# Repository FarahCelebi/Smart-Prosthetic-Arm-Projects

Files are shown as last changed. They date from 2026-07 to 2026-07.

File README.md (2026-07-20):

## Smart Prosthetic Arm

A six-project open hardware and firmware system for a surface EMG-controlled
prosthetic arm. The system reads muscle electrical signals from surface
electrodes, classifies hand gestures in real time, and drives a
servo-actuated prosthetic hand accordingly. Each project is a self-contained,
fully documented deliverable — schematic, PCB layout, Gerbers, and README —
designed to be fabricated and tested independently before integration.

## System Architecture

```
Surface electrodes
       │
       ▼
┌─────────────────┐
│  Project 1      │  EMG Acquisition Board
│  EMG signals    │  Dual-channel INA333 + ADS1115
│  → I²C out      │  Gain ~404×, 16-bit ADC
└────────┬────────┘
         │ I²C
         ▼
┌─────────────────┐
│  Project 2      │  Gesture Classifier Firmware
│  STM32 firmware │  Real-time EMG feature extraction
│  → gesture ID   │  + ML-based gesture classification
└────────┬────────┘
         │ I²C / UART
         ▼
┌─────────────────┐     ┌─────────────────┐
│  Project 3      │     │  Project 4      │
│  Servo Driver   │     │  BLE Module     │
│  PCA9685 PWM    │     │  nRF52840       │
│  6× servo out   │     │  Wireless telem │
└────────┬────────┘     └─────────────────┘
         │
         ▼
┌─────────────────┐
│  Project 5      │  IMU + EMG Sensor Fusion
│  ICM-42688-P    │  Accelerometer + gyroscope
│  + sensor fusion│  fused with EMG for robustness
└────────┬────────┘
         │
         ▼
┌─────────────────┐
│  Project 6      │  Full Integration Capstone
│  All subsystems │  Complete assembled arm system
│  integrated     │  End-to-end validation
└─────────────────┘
```

## Projects

| # | Project | Type | Description |
|---|---|---|---|
| 01 | [EMG Acquisition Board](./Project-1-EMG-Acquisition) | PCB | Dual-channel surface EMG acquisition board using INA333 instrumentation amplifiers and an ADS1115 16-bit ADC. Conditions raw muscle signals through a 404× gain chain with high-pass filtering and anti-alias filtering before I²C output. |
| 02 | [Gesture Classifier Firmware](./Project-2-Gesture-Classifier) | Firmware | Real-time gesture classification firmware running on the STM32F411, fusing dual-channel EMG features with ICM-42688-P IMU data to classify six hand gestures. Outputs servo position commands over I²C and streams telemetry to the BLE module over UART. |
| 03 | [Servo Driver Board](./Project-3-Servo-Driver) | PCB | PCA9685-based 16-channel PWM controller driving six servo motors for prosthetic hand finger and wrist actuation over I²C. Separate 5–6V servo power rail with 2000µF bulk capacitance isolates motor switching transients from the logic supply. |
| 04 | [BLE Telemetry Module](./Project-4-BLE-Telemetry-Module) | PCB | Bare nRF52840-QIAA BLE 5.0 transceiver board with full RF front-end design including pi-network antenna matching and quarter-wave wire antenna. Accepts USB or LiPo power through a dual-input OR-ing diode circuit with a low-dropout XC6210 LDO. |
| 05 | [IMU + EMG Sensor Fusion](./Project-5-IMU+EMG-Sensor-Fusion) | PCB | ICM-42688-P 6-axis IMU board providing wrist orientation and motion data over high-speed SPI to complement EMG signals in the gesture classifier. Includes an I²C passthrough header matching the EMG board pinout for minimal wiring harness on the arm. |
| 06 | [Full Integration Capstone](./Project-6-Full-Integration-Capstone) | PCB + Firmware | Central hub board hosting the STM32F411 main MCU and routing power, I²C, SPI, and UART signals between all five subsystem boards through pinout-matched connectors. Runs the gesture classifier firmware and coordinates the complete prosthetic arm system from a single 3.7V LiPo cell. |

## Hardware Stack

| Component | Role |
|---|---|
| INA333 (×2) | Instrumentation amplifier |
| ADS1115 | 16-bit I²C ADC |
| TLV2372 | Second-stage op-amp |
| PCA9685PW | 16-channel PWM servo controller |
| nRF52840 | BLE 5.0 + ARM Cortex-M4 |
| ICM-42688-P | 6-axis IMU (accelerometer + gyroscope) |

## Tools

- KiCad (PCB design)
- GitHub Desktop (version control)
- Zephyr RTOS / STM32 HAL (firmware)

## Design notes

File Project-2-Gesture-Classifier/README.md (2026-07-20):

# Gesture-Classifier-Firmware

Real-time hand gesture classification firmware for the Smart Prosthetic Arm
system, designed as Project 2 of 6. Running on the STM32F411RETx integration
board, the firmware reads dual-channel EMG signals from the ADS1115 ADC over
I²C, reads 6-axis inertial data from the ICM-42688-P IMU over SPI, fuses
both sensor streams to classify one of six hand gestures, drives the PCA9685
servo controller over I²C to actuate the prosthetic hand, and streams
telemetry to the nRF52840 BLE module over UART — all in a continuous
real-time loop.

## Repository Structure

```
Project-2-Gesture-Classifier/
├── README.md
└── Integration-Capstone/
    └── Core/
        ├── Inc/
        │   ├── emg.h
        │   ├── imu.h
        │   ├── classifier.h
        │   ├── servo.h
        │   └── ble.h
        └── Src/
            ├── main.c
            ├── emg.cpp
            ├── imu.cpp
            ├── classifier.cpp
            ├── servo.cpp
            └── ble.cpp
```

## System Architecture

```
ADS1115 (I²C1, 0x48)          ICM-42688-P (SPI1)
        │                              │
        ▼                              ▼
  emg.cpp                        imu.cpp
  - Read CH0, CH1                - Read accel x/y/z
  - Collect 200-sample window    - Read gyro x/y/z
  - Compute RMS, MAV             - Scale to g and °/s
        │                              │
        └──────────┬───────────────────┘
                   ▼
            classifier.cpp
            - Threshold-based gesture ID
            - 6 gestures: REST, GRIP, PINCH,
              POINT, PRONATE, SUPINATE
                   │
        ┌──────────┴──────────┐
        ▼                     ▼
   servo.cpp              ble.cpp
   PCA9685 (I²C1, 0x40)  nRF52840 (UART1)
   6-channel PWM          Telemetry packet
   finger/wrist control   G, E1, E2, AX, AY, AZ, GZ
```

## Gesture Definitions

| ID | Gesture | EMG Signature | IMU Signature |
|---|---|---|---|
| 0 | REST | Both channels quiet (<200 RMS) | Any |
| 1 | GRIP | Both channels active (>400 RMS) | Neutral |
| 2 | PINCH | CH2 dominant (>1.5× CH1) | Neutral |
| 3 | POINT | CH1 dominant (>1.5× CH2) | Neutral |
| 4 | PRONATE | CH1 moderate | Gyro Z > +50 °/s |
| 5 | SUPINATE | CH1 moderate | Gyro Z < -50 °/s |

## Design Notes

**Two-phase classifier architecture:** Phase 1 (this implementation) uses a
threshold-based classifier — fast, deterministic, and requires no training
data. EMG features (RMS and MAV per channel) are computed over a 200-sample
window at 860 SPS from the ADS1115, giving a feature update rate of
approximately 4Hz. IMU data is sampled once per gesture cycle. Phase 2 will
replace the threshold classifier with a support vector machine or lightweight
neural network trained on labelled EMG/IMU data collected using the SDMMC
Logger board (Project 3), improving classification accuracy for ambiguous
gestures.

**Sensor fusion rationale:** Surface EMG signals alone cannot reliably
distinguish pronation from supination or wrist-neutral gestures, since the
forearm muscle activation patterns overlap. The ICM-42688-P gyroscope Z-axis
provides the wrist rotation signal that resolves this ambiguity — the IMU
acts as a tie-breaker for gestures that EMG features cannot separate cleanly.

**EMG feature extraction:** Two features are computed per channel per window.
RMS (root mean square) captures signal energy and correlates with muscle
contraction force. MAV (mean absolute value) is computationally cheaper and
tracks signal amplitude. Both are computed in emg.cpp using integer
accumulation before a single sqrtf call, minimising floating point load on
the Cortex-M4F.

**ADS1115 sampling:** The ADS1115 is operated in single-shot mode at 860
SPS. Each channel conversion is triggered by writing the config register,
followed by a 2ms delay and a register read. With 200 samples per channel
per window, total EMG acquisition time is approximately 800ms per cycle.
Future optimisation will use the ALERT/RDY pin for interrupt-driven sampling,
removing the HAL_Delay calls and enabling higher effective sample rates.

**ICM-42688-P interface:** The IMU is read over SPI1 at 8MHz. A burst read
of 12 bytes starting at the accelerometer output register retrieves all six
axes in one transaction. Raw 16-bit values are scaled to g (accel,
±2g range, 16384 LSB/g) and degrees per second (gyro, ±250°/s range,
131 LSB/°/s).

**PCA9685 servo control:** The PCA9685 is configured for 50Hz PWM output
using an internal prescaler value of 121. Each servo channel is set using
a pulse width between 205 counts (~1ms, full open) and 410 counts (~2ms,
full close), with 307 counts (~1.5ms) as the neutral position. Six channels
(LED0–LED5) drive one servo per finger and wrist.

**BLE telemetry format:** Each telemetry packet is a null-terminated ASCII
string transmitted over UART1 at 115200 baud to the nRF52840 BLE module.
Format: `G:%d,E1:%d,E2:%d,AX:%d,AY:%d,AZ:%d,GZ:%d\r\n` where EMG RMS
values are integer counts, accelerometer values are scaled ×100 (cm/s²
units), and gyroscope Z is scaled ×10 (0.1°/s units). Float formatting
is avoided as `--specs=nano.specs` disables float printf support by default
in the ARM GCC nano libc.

**Build system:** The project is generated by STM32CubeMX and built from
the Terminal using the GNU ARM toolchain bundled with STM32CubeIDE. C HAL
files are compiled with arm-none-eabi-gcc; application modules (emg.cpp,
imu.cpp, classifier.cpp, servo.cpp, ble.cpp) and main.c are compiled with
arm-none-eabi-g++ to enable C++14 features and resolve C/C++ Thumb
interworking. The final ELF is linked with arm-none-eabi-g++.

## Build Instructions

```bash
# Add toolchain to PATH (adjust version as needed)
export PATH="/Applications/STM32CubeIDE.app/Contents/Eclipse/plugins/\
com.st.stm32cube.ide.mcu.externaltools.gnu-tools-for-stm32.14.3.rel1.\
macosaarch64_1.0.0.202602081740/tools/bin:$PATH"

cd Integration-Capstone/Debug
make all
```

## Flash Instructions

Connect an ST-LINK V2 to the SWD header (J3 on the Integration Capstone
Board) and use STM32CubeProgrammer or the CubeIDE debugger to flash
`Integration-Capstone.elf`.

## Binary Size (Phase 1)

| Section | Size |
|---|---|
| text (flash) | 47,824 bytes |
| data (initialized) | 332 bytes |
| bss (zero-initialized RAM) | 9,388 bytes |

## Hardware Dependencies

| Board | Role | Interface |
|---|---|---|
| EMG Acquisition Board | EMG signal source | I²C1 (0x48) |
| IMU Sensor Fusion Board | Motion data | SPI1 + PA4 CS |
| Servo Driver Board | Hand actuation | I²C1 (0x40) |
| BLE Module | Wireless telemetry | UART1 115200 |

## Part of

Smart Prosthetic Arm — Project 2 of 6

## Tools

- STM32CubeMX (peripheral configuration)
- STM32CubeIDE (project structure)
- GNU ARM Toolchain 14.3 (compilation)
- C++14

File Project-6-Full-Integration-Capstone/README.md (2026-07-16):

# Integration-Capstone-Board

The central hub of the Smart Prosthetic Arm system, designed as Project 6
of 6. This board hosts the main STM32F411RETx microcontroller and provides
the physical connectors, power distribution, and signal routing that ties
all five subsystem boards into a unified wearable system — the EMG
Acquisition Board, Servo Driver Board, BLE Module, IMU Sensor Fusion Board,
and the Gesture Classifier firmware running on the STM32 itself.

## Schematic

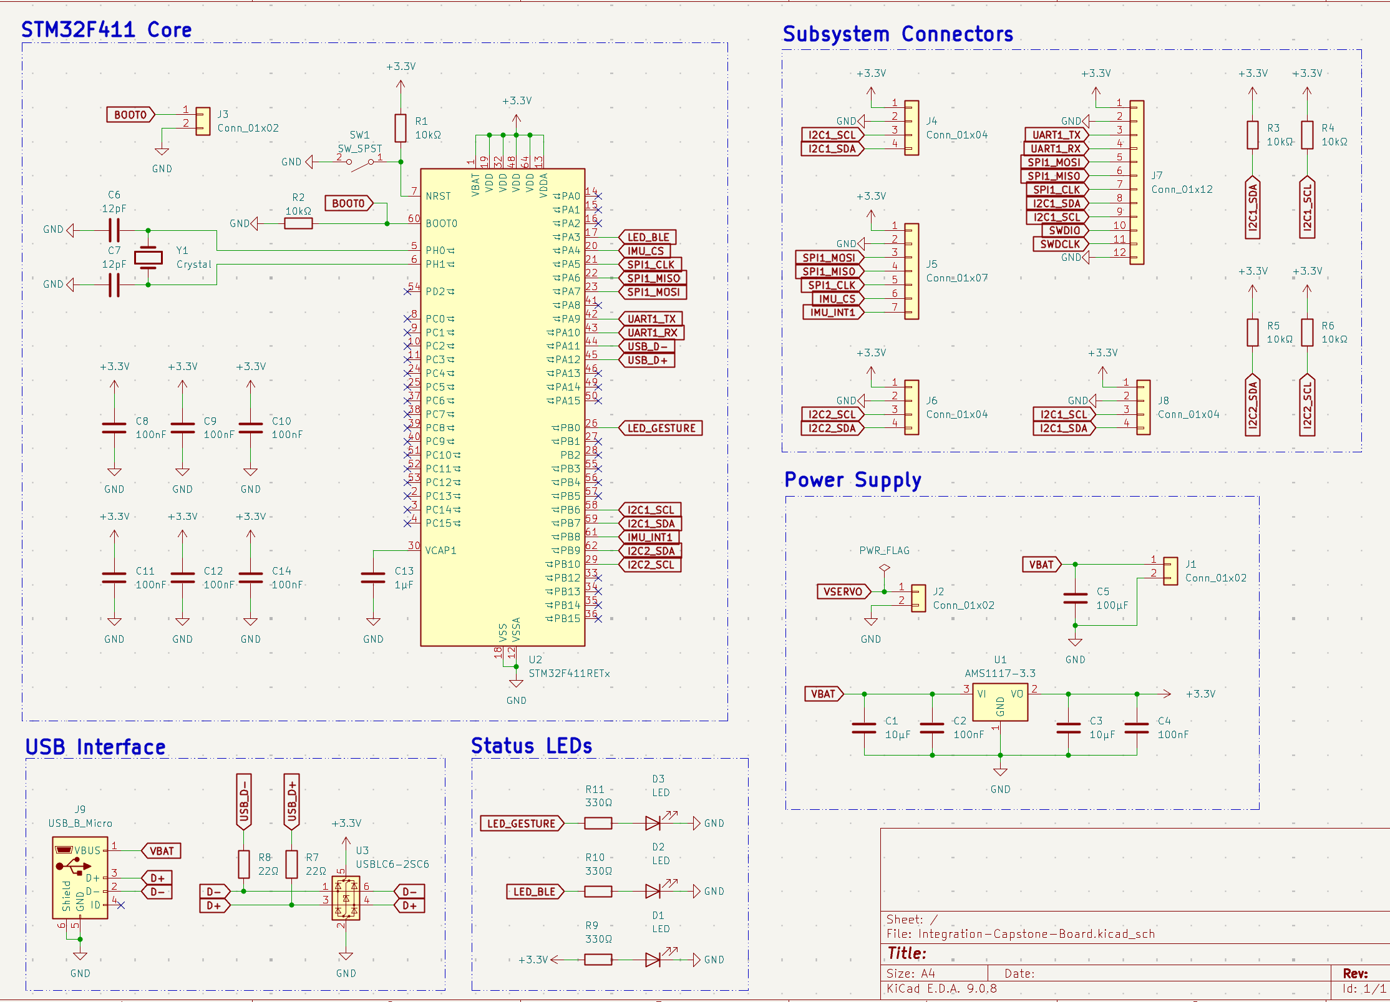
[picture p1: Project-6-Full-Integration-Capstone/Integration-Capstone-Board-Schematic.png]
Schematic


## PCB Layout

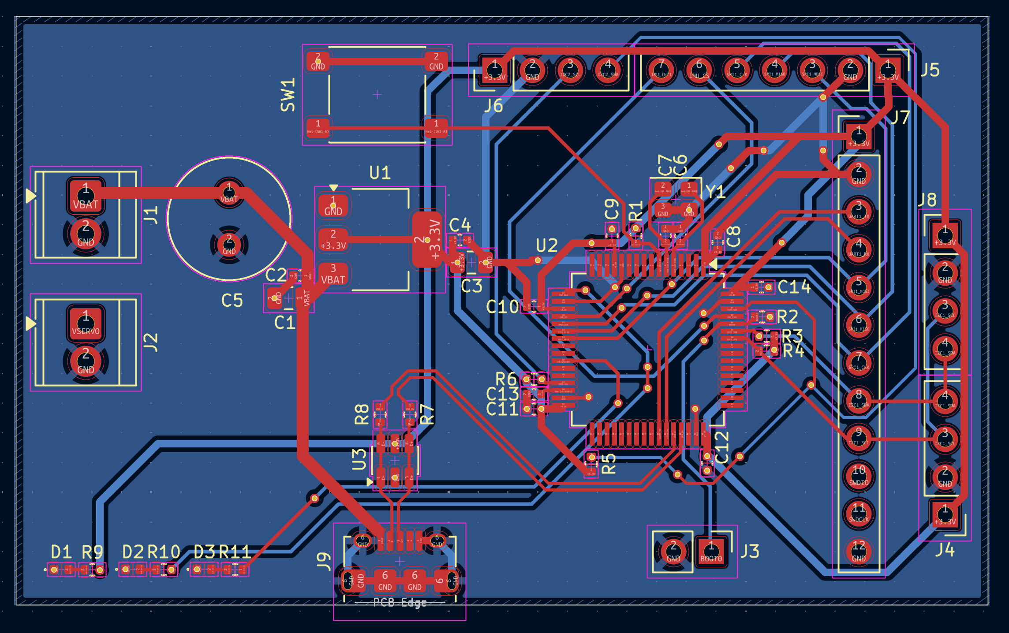
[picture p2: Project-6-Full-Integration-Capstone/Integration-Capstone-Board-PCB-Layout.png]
PCB Layout


## 3D View

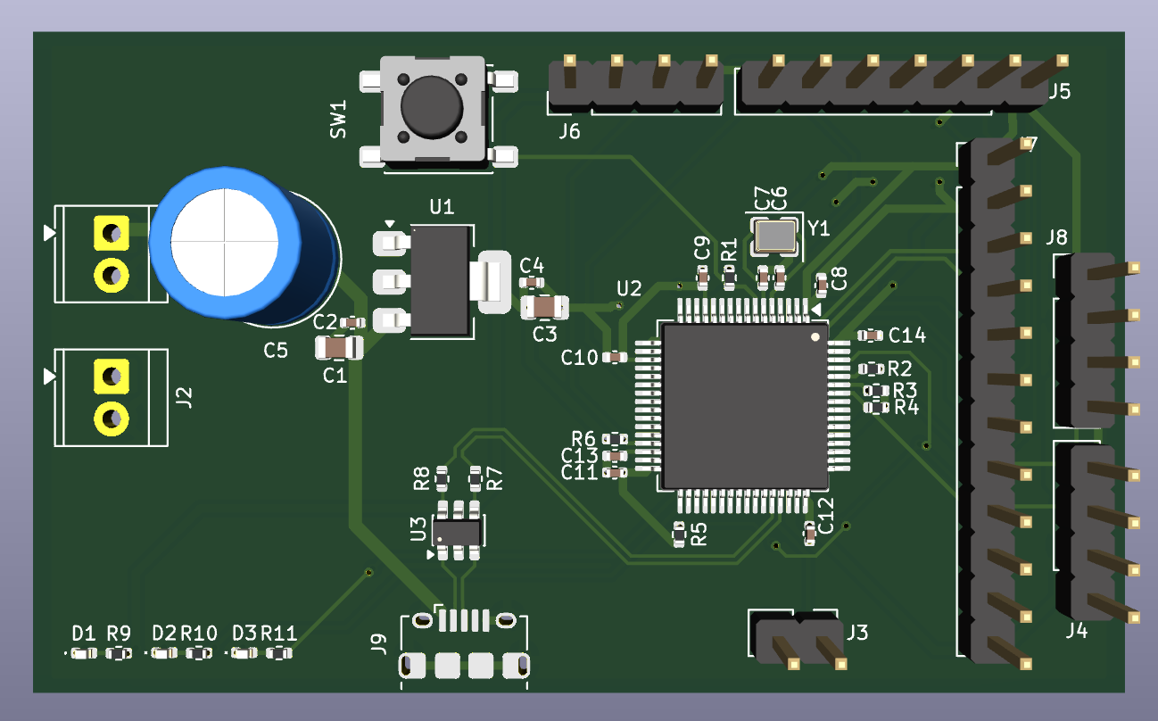
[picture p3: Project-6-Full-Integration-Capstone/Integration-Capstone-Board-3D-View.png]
3D View


## Overview

Rather than designing another standalone sensor or actuator board, the
capstone solves the real system integration challenge — making five
independent boards work together reliably as a wearable prosthetic arm.
The STM32F411 reads dual-channel EMG data from the ADS1115 over I²C,
reads 6-axis IMU data from the ICM-42688-P over SPI, classifies the
fused sensor data into one of six hand gestures, sends servo position
commands to the PCA9685 over I²C, and streams telemetry to the nRF52840
BLE module over UART — all concurrently, from a single board running on
a 3.7V LiPo battery.

## System Connections

| Connector | Subsystem | Interface | Pinout match |
|---|---|---|---|
| J4 | EMG Acquisition Board | I²C1 | Matches EMG board J3 |
| J5 | IMU Sensor Fusion Board | SPI1 + INT1 | Matches IMU board J2 |
| J6 | IMU I²C Passthrough | I²C2 | Matches IMU board J3 |
| J7 | BLE Module | UART1 + SPI1 + I²C1 + SWD | Matches BLE board J3 |
| J8 | Servo Driver Board | I²C1 | Matches servo driver J9 |
| J9 | USB | Programming + CDC | Micro-B |

All connector pinouts were designed from the start of the project to match
across boards — plugging any subsystem board into its corresponding header
requires no adapter and no rewiring.

## Design Notes

**Dual I²C bus architecture:** The STM32F411 has two I²C peripherals. I²C1
(PB6/PB7) is the main system bus, shared between the EMG Acquisition Board
(ADS1115, address 0x48), the Servo Driver Board (PCA9685, address 0x40),
and the BLE module's I²C lines. I²C2 (PB10/PB11) is a dedicated bus for
the IMU board's I²C passthrough header — isolating the IMU's local I²C
traffic from the main system bus prevents address conflicts and reduces bus
loading. Separate 10kΩ pull-up pairs (R3/R4 for I²C1, R5/R6 for I²C2)
are placed immediately beside their respective connectors.

**SPI bus sharing:** SPI1 (PA5/PA6/PA7) is shared between the IMU Sensor
Fusion Board (J5) and the BLE module (J7). The IMU chip select (IMU_CS on
PA4) and the BLE module's SPI CS are managed independently by the firmware,
allowing both devices on the same SPI bus without conflict. SPI was chosen
for the IMU over I²C to allow data rates up to 24MHz — necessary for high
ODR IMU sampling concurrent with BLE activity.

**Power architecture:** A single LiPo cell (3.7V nominal) connects to J1.
The AMS1117-3.3 LDO (U1) regulates this to 3.3V for the STM32, crystal,
and all subsystem connector power pins. A 100µF bulk electrolytic capacitor
(C5) is placed immediately at J1 to handle inrush current during system
startup when all five subsystem boards power up simultaneously. J2 is a
separate screw terminal for the 6V servo power rail — this passes directly
to the Servo Driver Board via cable and is never routed across the
integration board's PCB, keeping high-current servo switching noise isolated
from the logic rail.

**Crystal and USB:** A 25MHz crystal (Y1) provides the STM32's PLL
reference for accurate USB CDC operation. Load capacitors C6 and C7 (12pF
each) are placed immediately beside PH0 and PH1 with no vias on the
oscillator traces. USB D+ and D− pass through the USBLC6-2SC6 ESD
protection device (U3) placed immediately adjacent to J9, then through 22Ω
series resistors before reaching PA11 and PA12. The USB VBUS pin connects
to the VBAT net — when USB is connected it powers the board directly,
supplementing or replacing the LiPo without additional power management
circuitry.

**Reset and boot:** SW1 is a tactile push button connected to NRST with a
10kΩ pull-up to +3.3V, placed close to U2's NRST pin to minimise the reset
trace length. R2 pulls BOOT0 low by default for normal flash execution mode.
J3 is a 2-pin BOOT0 header that allows the STM32 to be put into DFU mode
by bridging pin 1 to +3.3V — used for initial firmware flashing before the
USB CDC interface is operational.

**Status LEDs:** Three LEDs provide system state visibility. D1 (green,
always on) connects directly from +3.3V through R9 — it illuminates
whenever the board is powered, requiring no firmware. D2 (blue) is driven
by PA3 through R10 and is toggled by firmware to indicate an active BLE
connection. D3 (yellow) is driven by PB0 through R11 and pulses on each
recognised gesture event. All three resistors are 330Ω giving approximately
8mA LED current at 3.3V supply — visible in indoor and outdoor conditions
without excessive current draw from the battery.

**Stackup rationale:** F.Cu carries all signal and power traces with no
copper pour. B.Cu carries a solid unbroken GND plane across the entire
board. This gives every signal trace — including the dense I²C, SPI, and
UART routing between U2 and the subsystem connectors — a direct return path
immediately beneath it, minimising crosstalk between the parallel bus
signals. A minimum of 4 vias are placed through the STM32's exposed GND pad
to the B.Cu plane for both electrical and thermal connection. Stitching vias
connect the board edge GND connections to the B.Cu plane around the
perimeter.

## GPIO Map

| GPIO | Function | Destination |
|---|---|---|
| PA3 | LED_BLE | D2 blue LED |
| PA4 | IMU_CS | J5 pin 6 |
| PA5 | SPI1_CLK | J5 pin 5, J7 pin 7 |
| PA6 | SPI1_MISO | J5 pin 4, J7 pin 6 |
| PA7 | SPI1_MOSI | J5 pin 3, J7 pin 5 |
| PA9 | UART1_TX | J7 pin 3 |
| PA10 | UART1_RX | J7 pin 4 |
| PA11 | USB_DM | J9 D− |
| PA12 | USB_DP | J9 D+ |
| PB0 | LED_GESTURE | D3 yellow LED |
| PB6 | I2C1_SCL | J4 pin 3, J7 pin 9, J8 pin 3 |
| PB7 | I2C1_SDA | J4 pin 4, J7 pin 8, J8 pin 4 |
| PB8 | IMU_INT1 | J5 pin 7 |
| PB9 | I2C2_SDA | J6 pin 4 |
| PB10 | I2C2_SCL | J6 pin 3 |
| PH0 | OSC_IN | Y1 pin 1 |
| PH1 | OSC_OUT | Y1 pin 2 |

## Manufacturing

- 2-layer stackup: F.Cu (signal + power) / B.Cu (solid GND plane)
- 1.6mm FR4, standard 1oz copper
- Passed DRC with 0 violations, 0 unconnected nets
- Gerbers and drill files generated

## Part of

Smart Prosthetic Arm — Project 6 of 6

## Tools

- KiCad

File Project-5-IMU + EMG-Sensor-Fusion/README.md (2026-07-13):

# IMU-Sensor-Fusion-Board

A TDK InvenSense ICM-42688-P based 6-axis IMU board designed as Project 5
of the Smart Prosthetic Arm system. The board adds wrist orientation and
motion context to the dual-channel EMG signals from the EMG Acquisition
Board, enabling the gesture classifier firmware to distinguish between
gestures that produce similar EMG patterns but differ in wrist orientation —
significantly improving real-world classification accuracy.

## Schematic

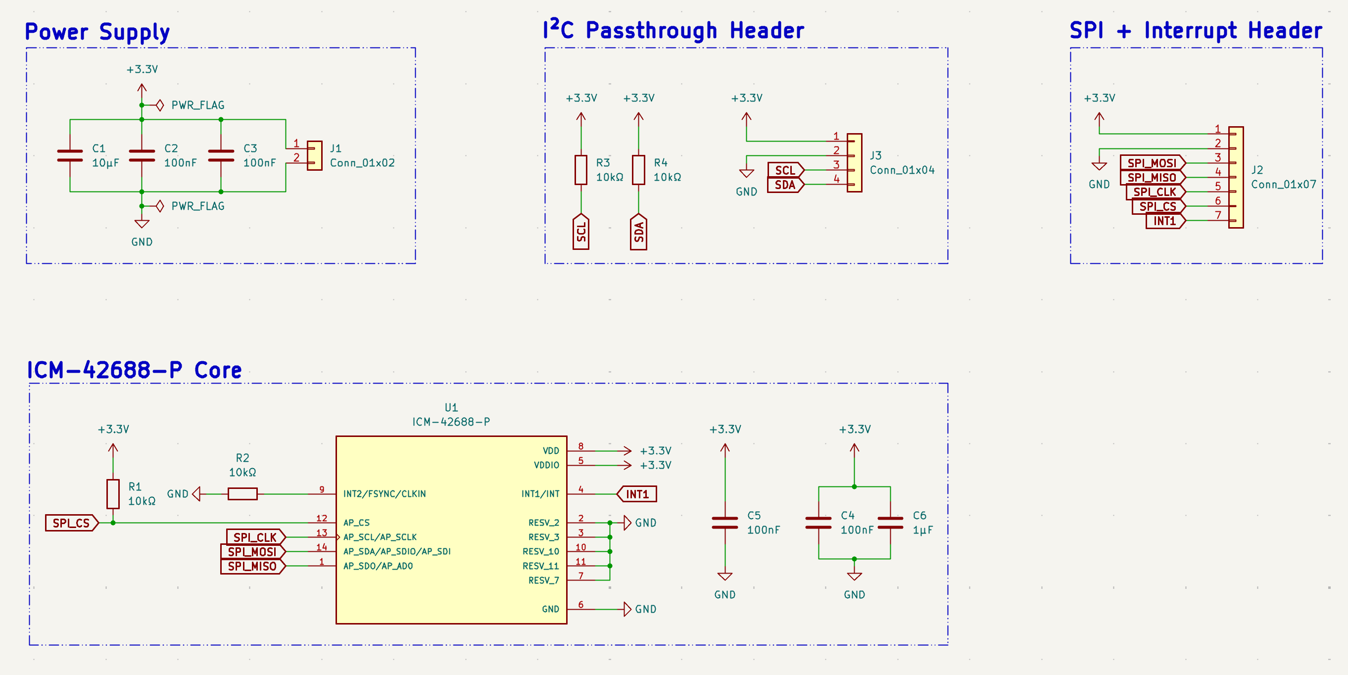
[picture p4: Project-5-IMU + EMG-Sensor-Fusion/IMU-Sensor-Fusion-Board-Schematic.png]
Schematic


## PCB Layout

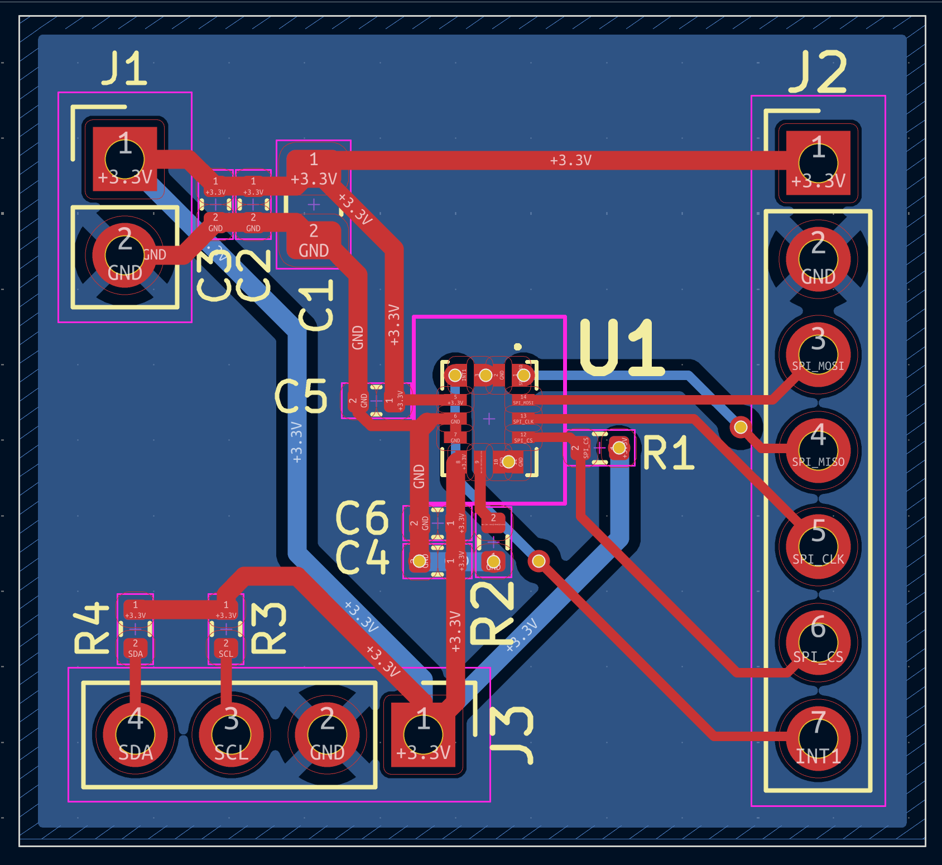
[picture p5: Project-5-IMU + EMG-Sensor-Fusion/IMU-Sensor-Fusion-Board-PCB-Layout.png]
PCB Layout


## 3D View

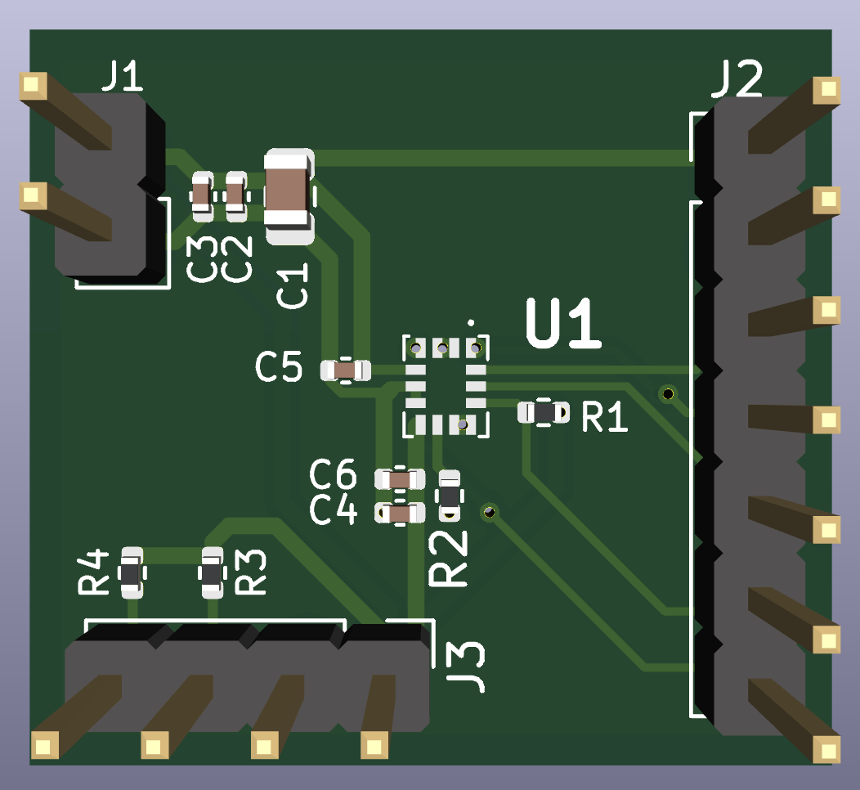
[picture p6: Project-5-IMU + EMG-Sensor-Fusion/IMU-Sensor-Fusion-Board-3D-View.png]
3D View


## Overview

The ICM-42688-P integrates a 3-axis gyroscope and 3-axis accelerometer in a
compact 2.5×3.0mm LGA-14 package, providing full 6-axis motion data over a
high-speed SPI interface at up to 24MHz. The board exposes the SPI bus,
chip select, and both interrupt lines through a 7-pin header for direct
connection to the host microcontroller, and passes through the I²C bus on a
4-pin header matching the EMG Acquisition Board pinout — allowing the host
to communicate with the ADS1115 ADC and the IMU simultaneously without
additional wiring.

## Design Notes

**IMU selection:** The ICM-42688-P was selected over lower-tier IMUs such as
the MPU6050 for several reasons directly relevant to prosthetic arm use. Its
gyroscope noise density of 2.8 mdps/√Hz and accelerometer noise density of
65 µg/√Hz are among the lowest available in a single-package 6-axis device,
enabling detection of subtle wrist rotation and fine finger-positioning
gestures that would be buried in noise on a less capable sensor. The device
also supports output data rates up to 32kHz, providing substantial
oversampling headroom for the sensor fusion algorithm. The 1.71–3.6V supply
range is directly compatible with the 3.3V system rail without a dedicated
LDO.

**SPI interface:** The ICM-42688-P is operated in 4-wire SPI mode. AP_CS
(pin 12) is the chip select, held high by R1 (10kΩ pull-up to +3.3V) when
the bus is idle. AP_SCL/AP_SCLK (pin 13) is the clock, AP_SDA/AP_SDI
(pin 14) is MOSI, and AP_SDO/AP_AD0 (pin 1) is MISO. In SPI mode the
AP_AD0 function of pin 1 is overridden by the chip select state at power-up
— AP_CS tied high ensures SPI mode is selected correctly.

**Reserved pin handling:** The ICM-42688-P datasheet specifies explicit
requirements for each reserved pin. RESV_7 (pin 7) must be connected to GND
— this is mandatory and not optional. RESV_2 (pin 2) and RESV_3 (pin 3) may
be left unconnected or tied to GND — both are tied to GND on this board for
noise immunity. RESV_10 (pin 10) and RESV_11 (pin 11) may be left
unconnected — no-connect flags are placed on both.

**FSYNC/CLKIN pin (pin 9):** The INT2/FSYNC/CLKIN pin serves three functions
depending on firmware configuration. Since frame sync and external clock are
not used in this design, the pin is held low through a 10kΩ pull-down
resistor (R2) to GND. A direct GND connection was avoided because the
SnapEDA symbol defines pin 9 as bidirectional — connecting it directly to a
power symbol generates a KiCad ERC pin-type conflict. The pull-down resistor
resolves the conflict while satisfying the datasheet requirement to hold the
pin low when unused.

**Interrupt lines:** INT1 (pin 4) is broken out to pin 7 of the SPI header
as the primary data-ready interrupt — the host firmware configures INT1 to
assert when new accelerometer and gyroscope data is available in the output
registers, enabling interrupt-driven sampling without polling. INT2 is not
connected on this board — it is available for future use via firmware
reconfiguration if a second interrupt source is needed.

**Power supply and decoupling:** The board accepts 3.3V directly with no
onboard LDO. Three decoupling capacitors are placed at the power input: C1
(10µF bulk), C2 (100nF ceramic), C3 (100nF ceramic). At the ICM-42688-P
VDD pin (pin 8): C5 (100nF) and C6 (1µF) are placed as close as physically
possible to the pin. At VDDIO (pin 5): C4 (100nF) is placed immediately
adjacent. Keeping VDD and VDDIO decoupling separate and local is important
for a MEMS sensor — shared decoupling allows switching noise on the digital
IO rail to couple into the analog sensor supply, increasing noise floor on
both accelerometer and gyroscope outputs.

**I²C passthrough:** J3 is a 4-pin header (+3.3V, GND, SCL, SDA) with
pinout identical to the EMG Acquisition Board's J3 and the SDMMC Logger's
J4. Pull-up resistors R3 and R4 (10kΩ each to +3.3V) are placed immediately
beside J3. This header allows the host to reach the ADS1115 on the EMG board
over the same I²C bus without an additional cable run, keeping the wiring
harness on the prosthetic arm minimal.

**Stackup rationale:** F.Cu carries all signal and power traces with no
copper pour. B.Cu carries a solid unbroken GND plane across the entire board.
This gives every signal trace a direct return path immediately beneath it —
particularly important for the SPI clock and data lines where a fragmented
return path would increase crosstalk between channels. Stitching vias connect
the board edge GND connections to the B.Cu plane around the perimeter.

## Interface Headers

**J2 — SPI + Interrupt (Conn_01x07):**

| Pin | Signal |
|---|---|
| 1 | +3.3V |
| 2 | GND |
| 3 | SPI_MOSI |
| 4 | SPI_MISO |
| 5 | SPI_CLK |
| 6 | SPI_CS |
| 7 | INT1 |

**J3 — I²C Passthrough (Conn_01x04):**

| Pin | Signal |
|---|---|
| 1 | +3.3V |
| 2 | GND |
| 3 | SCL |
| 4 | SDA |

## Manufacturing

- 2-layer stackup: F.Cu (signal + power) / B.Cu (solid GND plane)
- 1.6mm FR4, standard 1oz copper
- Passed DRC with 0 violations, 0 unconnected nets
- Gerbers and drill files generated

## Part of

Smart Prosthetic Arm — Project 5 of 6

## Tools

- KiCad

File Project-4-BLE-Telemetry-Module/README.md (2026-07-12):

# BLE-Module-Board

A Nordic nRF52840-based Bluetooth Low Energy 5.0 telemetry module designed
as Project 4 of the Smart Prosthetic Arm system. The board receives gesture
commands and EMG telemetry from the prosthetic arm system and transmits them
wirelessly to a smartphone or PC for real-time monitoring, configuration, and
data logging. It also serves as a wireless command receiver, enabling remote
arm configuration without a physical connection.

## Schematic

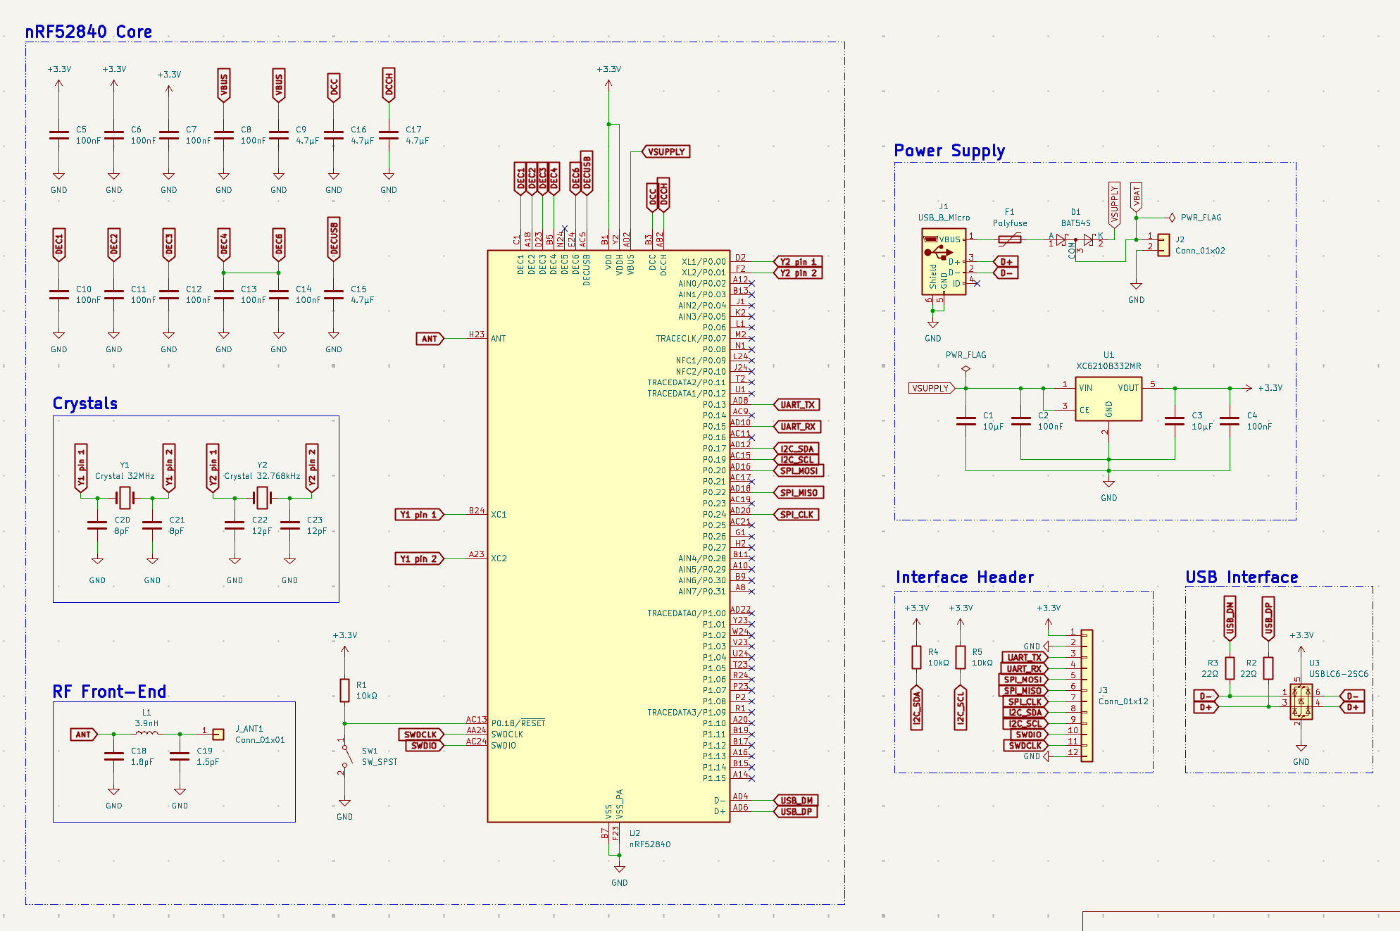
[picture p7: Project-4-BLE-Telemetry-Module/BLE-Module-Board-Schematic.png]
Schematic


## PCB Layout

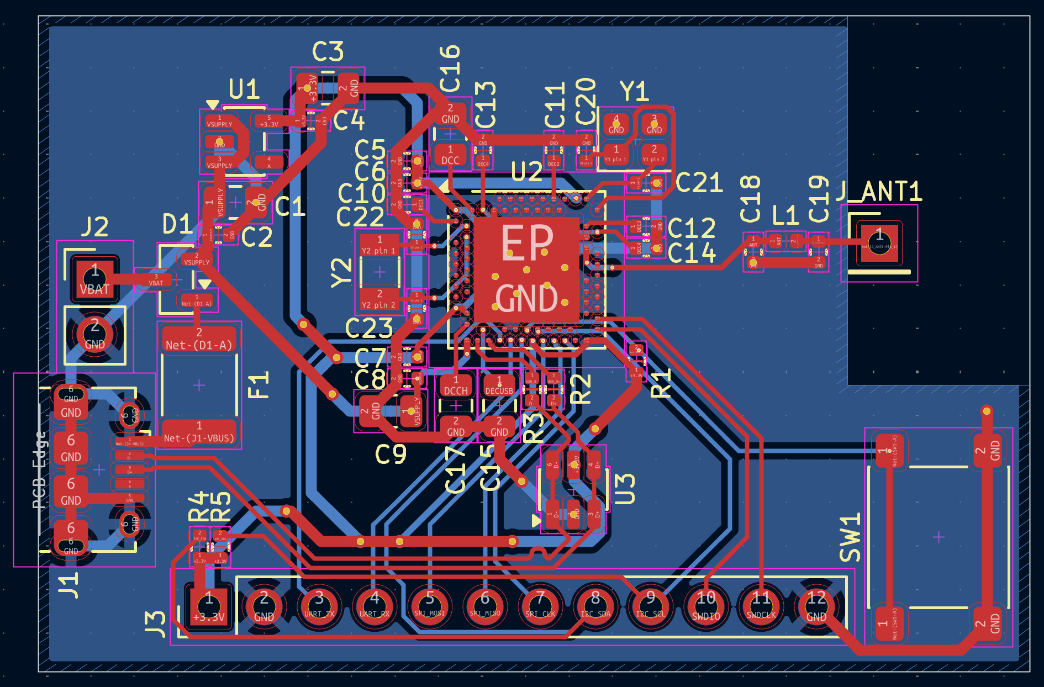
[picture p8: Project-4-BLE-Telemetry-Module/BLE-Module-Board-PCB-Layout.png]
PCB Layout


## 3D View

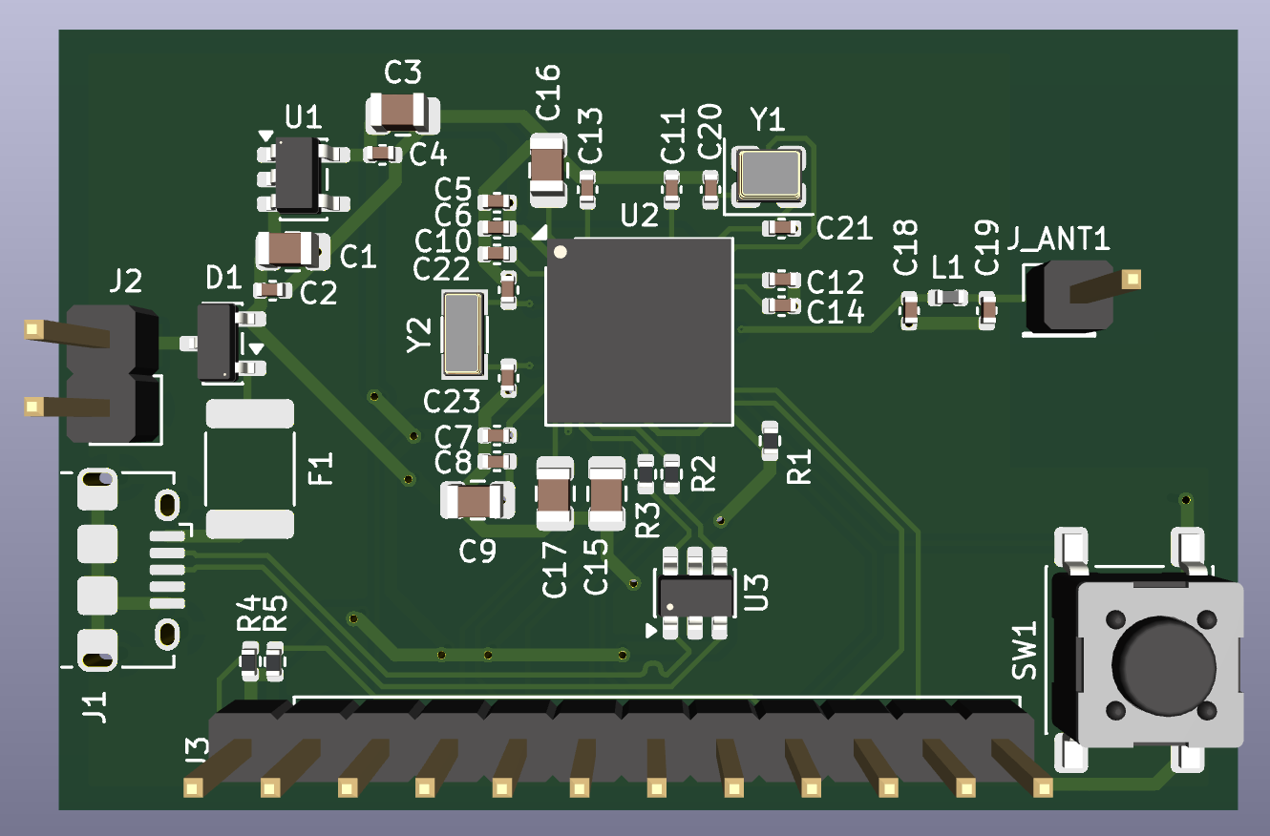
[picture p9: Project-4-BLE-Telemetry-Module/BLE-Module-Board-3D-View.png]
3D View


## Overview

The nRF52840 integrates a 2.4GHz BLE 5.0 radio, an ARM Cortex-M4F processor,
USB device controller, and extensive GPIO peripherals in a single aQFN-73
package. This board exposes the full interface set — UART, SPI, I²C, SWD, and
power — through a single 12-pin header, matching the pinout conventions of the
EMG Acquisition Board and SDMMC Logger for direct cable connection across the
system. A dual-input power circuit accepts either USB (5V) or a 3.7V LiPo
battery, making the board suitable for both bench development and wearable
deployment on the prosthetic arm.

## Design Notes

**Bare IC vs pre-certified module:** The nRF52840-QIAA bare IC was chosen
over a pre-certified module such as the Holyiot or u-blox NINA-B3. A module
integrates the antenna and passes regulatory certification as a unit, which
simplifies deployment but reduces design transparency and portfolio value.
Using the bare IC requires designing the RF front-end and antenna matching
network explicitly, producing a more technically rigorous board and a stronger
demonstration of RF PCB design capability.

**Power architecture — dual input OR-ing:** The board accepts power from two
sources simultaneously without conflict. USB VBUS and LiPo VBAT each feed
one anode of a BAT54S dual Schottky diode in common-cathode configuration.
The higher voltage source conducts through its diode and feeds the VSUPPLY
net; the lower voltage source is blocked automatically. VSUPPLY feeds both
the XC6210B332MR LDO (generating 3.3V for all logic) and the nRF52840's
VBUS pin (enabling the internal USB 3.3V regulator when USB is connected).
When running from LiPo only, VSUPPLY is approximately 3.4V after the diode
drop — the LDO dropout of 75mV at this level still produces a stable 3.3V
output, and the USB regulator is simply inactive. This means BLE operation
continues from battery without interruption while USB programming requires
USB connection.

**LDO selection:** The XC6210B332MR was chosen over the AMS1117-3.3 used
on previous boards specifically for its 75mV dropout voltage versus the
AMS1117's 1.3V dropout. The AMS1117 would require a minimum 4.6V input to
regulate to 3.3V — far above a LiPo battery's end-of-discharge voltage of
3.0V. The XC6210 operates reliably from VSUPPLY down to approximately 3.375V,
covering the full usable LiPo range. The CE pin is tied permanently high to
keep the regulator enabled at all times.

**RF front-end and antenna matching:** The nRF52840 ANT pin connects to a
pi-network matching circuit before the antenna connection point J_ANT. The
network consists of a 1.8pF shunt capacitor to GND on the IC side, a 3.9nH
series inductor, and a 1.5pF shunt capacitor to GND on the antenna side.
These values are taken directly from the Nordic reference schematic for a
quarter-wave wire antenna at 2.4GHz, targeting 50Ω impedance at the antenna
feed point. The entire pi-network is placed in a straight horizontal line
between the ANT pin and J_ANT, within 10mm total path length, with GND vias
immediately beside each shunt capacitor pad to minimise return-path
inductance at 2.4GHz.

**Antenna keepout zone:** A rule area covering the top-right corner of the
board prohibits copper fills on both F.Cu and B.Cu within 5mm of J_ANT and
the wire antenna. The B.Cu GND plane stops at the keepout boundary. Copper
beneath or adjacent to the antenna would detune it by acting as a parasitic
reflector, shifting the resonant frequency away from 2.4GHz and reducing
radiated efficiency. The quarter-wave wire antenna (31.25mm, λ/4 at 2.4GHz)
connects to J_ANT and extends outside the keepout zone.

**Crystal oscillators:** The nRF52840 requires two external crystals. Y1
(32MHz, 2520 SMD package, 8pF load capacitance) provides the main RF and
CPU clock reference — placed within 3mm of XC1/XC2 with no vias on the
oscillator traces. Y2 (32.768kHz, 3215 SMD package, 12.5pF load capacitance)
provides the RTC clock for low-power sleep scheduling — placed beside XL1/XL2
with vias acceptable given the low operating frequency. Load capacitors for
both crystals are placed inline between the MCU pin and the crystal pad on
the MCU side.

**DEC4 and DEC6 connection:** The Nordic datasheet requires DEC4 and DEC6
to be directly connected to each other in addition to having individual 100nF
decoupling capacitors to GND. These pins are the 1.3V internal regulator
supply decoupling nodes — the direct connection between them is mandatory per
the datasheet and is implemented with a short trace between the two pads.

**USB ESD protection:** The USBLC6-2SC6 is placed immediately adjacent to J1,
providing transient voltage suppression on both D+ and D− before the 22Ω
series resistors that connect to the nRF52840's USB pins. ESD protection must
be at the connector — placing it midway along the trace reduces its
effectiveness.

**SWD debug interface:** SWDIO and SWDCLK are exposed on pins 10 and 11 of
the 12-pin interface header J3, alongside UART, SPI, I²C, power, and GND.
A single connector handles both runtime communication and firmware programming,
eliminating the need for a separate debug header.

**Stackup rationale:** F.Cu carries all signal and power traces with no copper
pour. B.Cu carries a solid unbroken GND plane across the entire board except
the antenna keepout zone. This gives every signal trace a direct return path
immediately beneath it — the optimal configuration for a 2-layer RF board.
Stitching vias connect the board edge GND connections to the B.Cu plane every
5mm around the perimeter. A minimum of 4 vias are placed through the nRF52840
exposed die pad to the B.Cu GND plane as required for both electrical and
thermal connection.

## Interface Header Pinout (J3)

| Pin | Signal |
|---|---|
| 1 | +3.3V |
| 2 | GND |
| 3 | UART_TX |
| 4 | UART_RX |
| 5 | SPI_MOSI |
| 6 | SPI_MISO |
| 7 | SPI_CLK |
| 8 | I2C_SDA |
| 9 | I2C_SCL |
| 10 | SWDIO |
| 11 | SWDCLK |
| 12 | GND |

## Manufacturing

- 2-layer stackup: F.Cu (signal + power) / B.Cu (solid GND plane)
- 1.6mm FR4, standard 1oz copper
- Antenna keepout zone: no copper on either layer within 5mm of J_ANT
- Passed DRC with 0 violations, 0 unconnected nets
- Gerbers and drill files generated

## Part of

Smart Prosthetic Arm — Project 4 of 6

## Tools

- KiCad

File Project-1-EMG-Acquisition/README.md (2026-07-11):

# EMG-Acquisition-Board

A dual-channel electromyography (EMG) signal acquisition board for surface
electrode input, designed as Project 1 of the Smart Prosthetic Arm system.
The board conditions raw muscle electrical signals into a clean, amplified,
digitised output suitable for real-time gesture classification firmware.

## Schematic

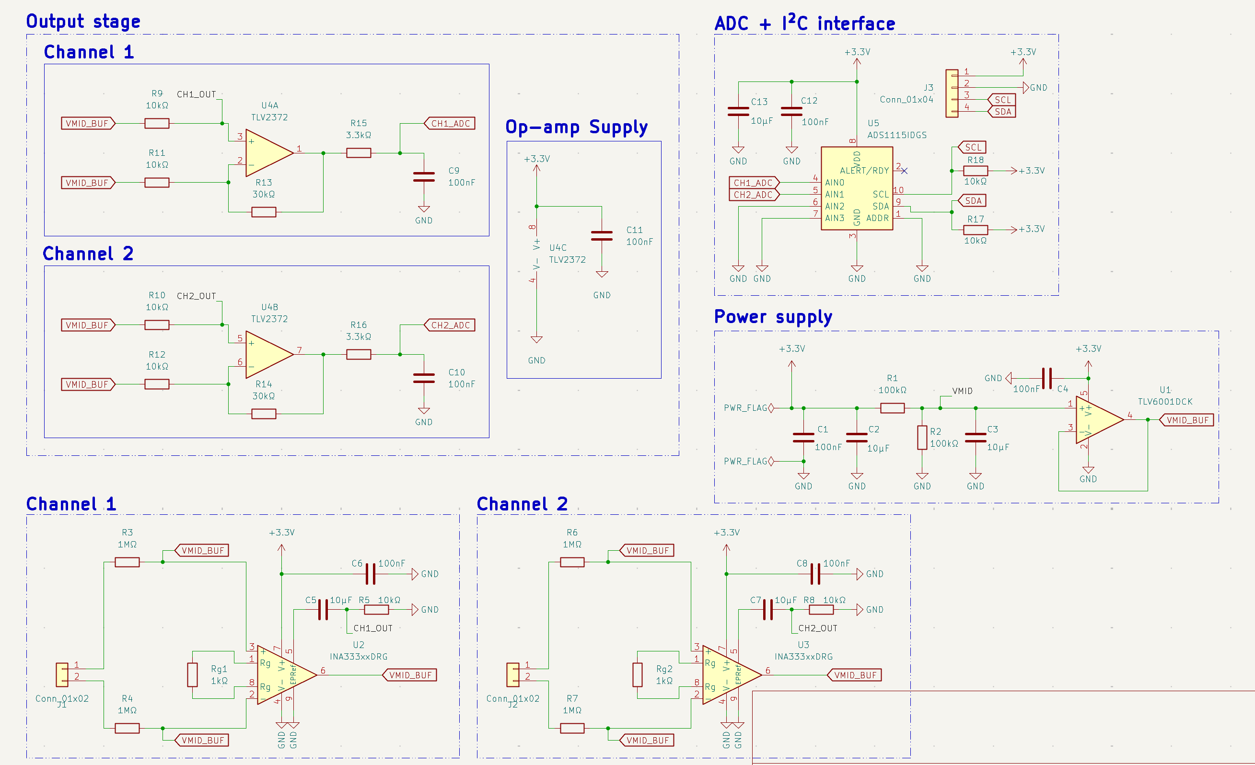
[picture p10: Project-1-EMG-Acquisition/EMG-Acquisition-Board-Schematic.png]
Schematic


## PCB Layout

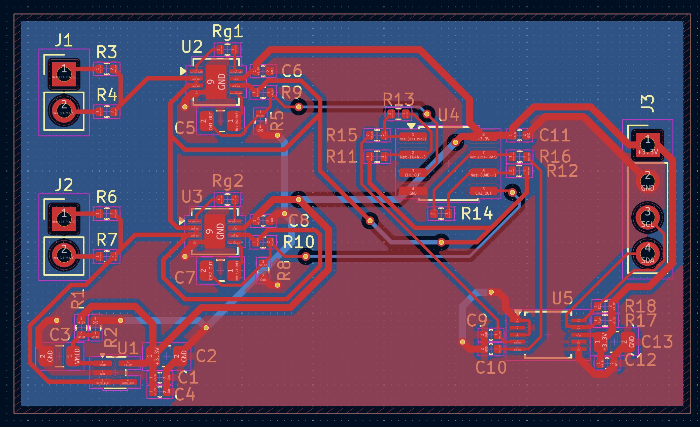
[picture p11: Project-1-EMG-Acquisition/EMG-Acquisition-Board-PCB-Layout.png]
PCB Layout


## 3D View

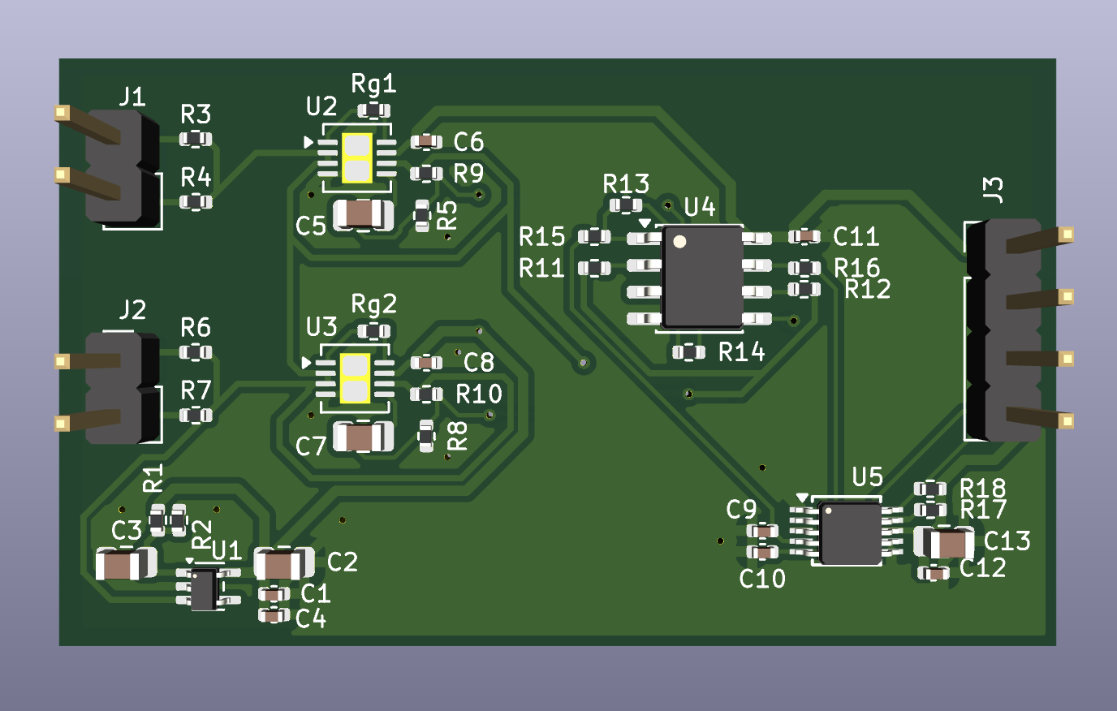
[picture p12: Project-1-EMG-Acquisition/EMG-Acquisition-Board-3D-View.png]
3D View


## Overview

Surface EMG signals are weak (50µV–5mV), heavily contaminated by DC electrode
offset, motion artefact, and 50Hz mains interference. This board addresses
each of these with a structured four-stage signal chain: differential
instrumentation amplification, AC coupling, a second gain stage, and
anti-alias filtering before a 16-bit I²C ADC. Total gain per channel is
approximately 404×, placing a 1mV EMG input at roughly 400mV at the ADC input
— well within the ADS1115's input range referenced to a 1.65V mid-rail.

## Design Notes

**Mid-rail bias generation:** The entire analog chain operates from a single
3.3V supply, which requires a stable 1.65V mid-rail reference to centre
signals within the supply range. A resistor divider (R1, R2 — 100kΩ each)
sets the VMID node at 1.65V, filtered by a 10µF capacitor (C3) to suppress
supply noise. A TLV6001DCK op-amp wired as a unity-gain voltage follower
buffers this reference (VMID_BUF), providing a low-impedance 1.65V rail that
drives the INA333 REF pins and the second-stage amplifier bias inputs. Without
the buffer, loading from the REF pins would pull VMID off its setpoint under
signal conditions.

**First-stage instrumentation amplifier:** Each channel uses an INA333 (SOIC-8)
configured for approximately 101× differential gain, set by a single 1kΩ gain
resistor (Rg) via the formula G = 1 + 100kΩ/Rg. The INA333 was selected for
its low offset voltage (25µV typical), low input bias current suitable for
high-impedance electrode sources, and single-supply rail-to-rail operation
down to 1.8V. The REF pin is tied to VMID_BUF on both channels, centering
the amplifier output at 1.65V. Input bias resistors (R3, R4 and R6, R7 —
1MΩ each) hold each differential input at VMID_BUF when no electrode is
connected, preventing the instrumentation amplifier inputs from floating and
the output from railing.

**AC coupling and high-pass filter:** The INA333 output passes through an RC
high-pass filter (C5/C7 — 10µF, R5/R8 — 10kΩ) with a cutoff frequency of
approximately 1.6Hz, calculated as f = 1/(2π × 10kΩ × 10µF). This removes
the residual DC electrode offset that survives the differential stage —
typically several hundred millivolts in practical electrode setups — while
passing all physiologically relevant EMG content above 20Hz with minimal
attenuation.

**Second-stage amplifier:** A TLV2372 dual op-amp (SOIC-8) provides 4×
additional gain per channel in a non-inverting topology, with the output
biased at VMID_BUF through the lower feedback resistor. Gain is set by the
ratio 1 + R13/R11 = 1 + 30kΩ/10kΩ = 4×. This stage also drives the
anti-alias filter, which a high-output-impedance source such as the RC filter
output could not do reliably.

**Anti-alias filter:** A first-order RC low-pass filter (R15/R16 — 3.3kΩ,
C9/C10 — 100nF) on each channel output sets the anti-alias cutoff at
approximately 480Hz, calculated as f = 1/(2π × 3.3kΩ × 100nF). This sits
just below the Nyquist frequency for a 1kHz ADC sampling rate, suppressing
out-of-band noise and aliasing artefacts before the signal reaches the ADC
input.

**ADC and I²C interface:** The ADS1115IDGS (MSOP-10) is a 16-bit successive-
approximation ADC with an internal programmable gain amplifier and I²C
interface. Channels AIN0 and AIN1 receive CH1_ADC and CH2_ADC respectively;
AIN2 and AIN3 are tied to GND. The ADDR pin is tied to GND, setting the I²C
address to 0x48. VDD is decoupled with a 100nF ceramic capacitor and a 10µF
bulk capacitor. I²C pull-up resistors (R17, R18 — 10kΩ each to +3.3V) are
placed immediately adjacent to J3, the 4-pin I²C header (VCC, GND, SCL, SDA),
which connects to the host microcontroller.

**Signal chain summary:**

| Stage | Component | Gain / Function |
|---|---|---|
| Instrumentation amp | INA333 × 2 | 101× differential |
| High-pass filter | RC (10µF, 10kΩ) | −3dB at 1.6Hz |
| Second stage | TLV2372 × 2 | 4× non-inverting |
| Anti-alias filter | RC (100nF, 3.3kΩ) | −3dB at 480Hz |
| ADC | ADS1115 | 16-bit, I²C, 0x48 |
| **Total gain** | | **~404×** |

## Manufacturing

- 2-layer stackup: F.Cu (signal + power) / B.Cu (GND plane)
- 1.6mm FR4, standard 1oz copper
- Passed DRC with 0 violations, 0 unconnected nets
- Gerbers and drill files generated

## Part of

Smart Prosthetic Arm — Project 1 of 6

## Tools

- KiCad

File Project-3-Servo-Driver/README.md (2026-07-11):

# Servo-Driver-Board

A PCA9685-based 16-channel PWM servo controller board designed as Project 3
of the Smart Prosthetic Arm system. The board receives motion commands over
I²C from a host microcontroller and drives up to 6 servo motors — one per
finger and one for wrist rotation — providing the full actuation layer of the
prosthetic hand.

## Schematic

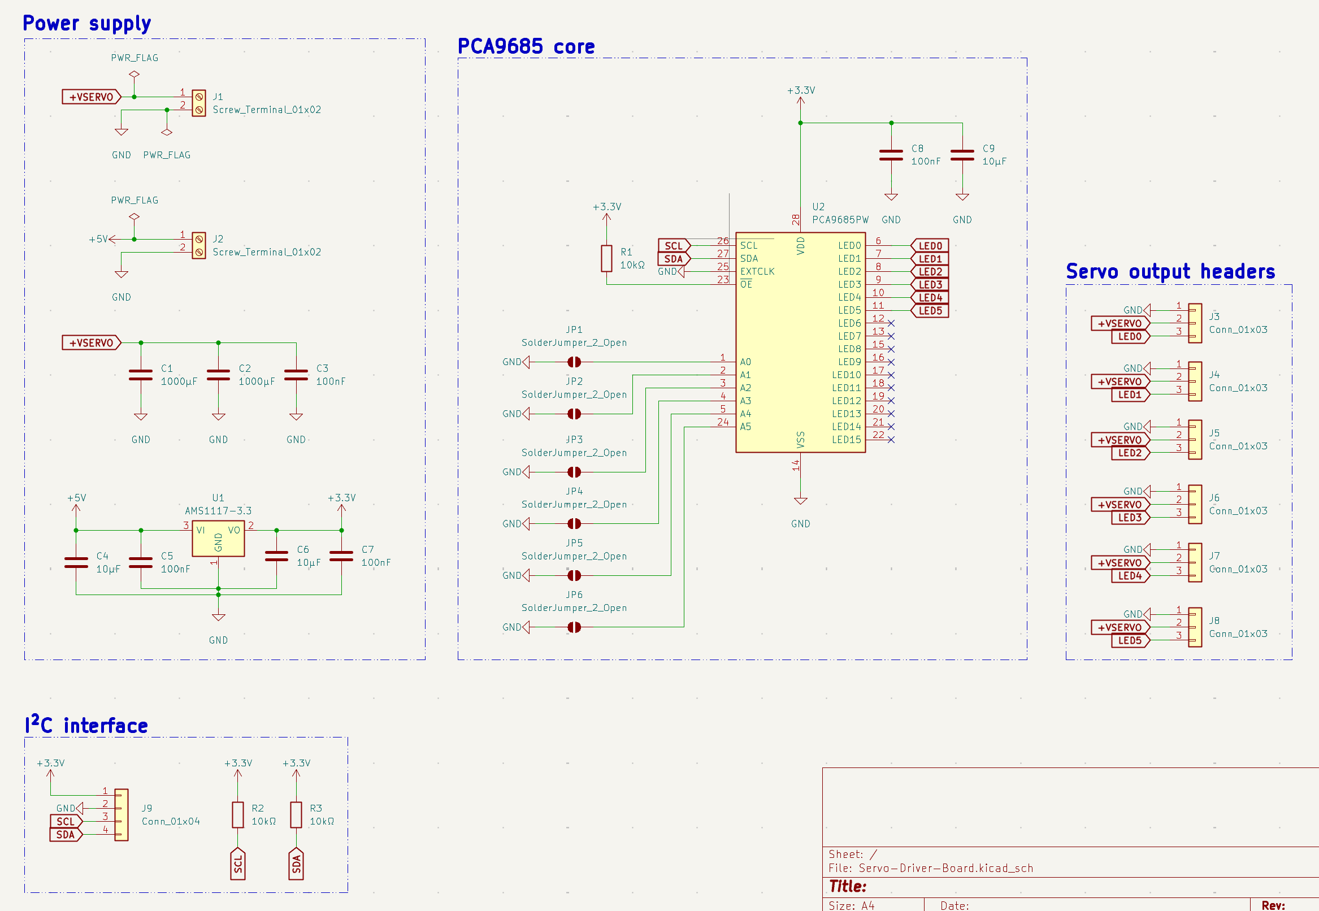
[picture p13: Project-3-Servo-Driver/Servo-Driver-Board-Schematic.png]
Schematic


## PCB Layout

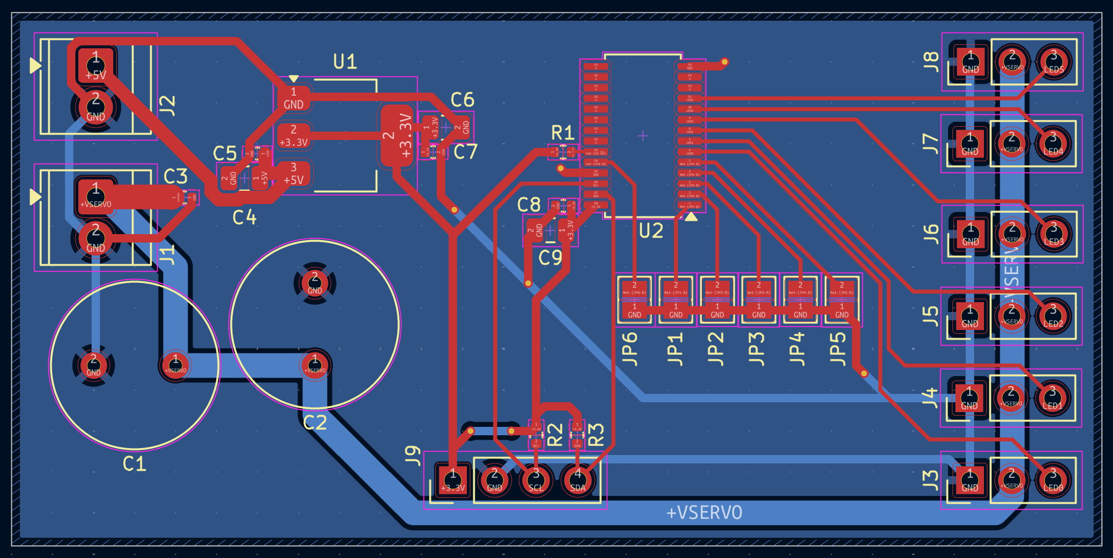
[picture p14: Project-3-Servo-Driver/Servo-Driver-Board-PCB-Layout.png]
PCB Layout


## 3D View

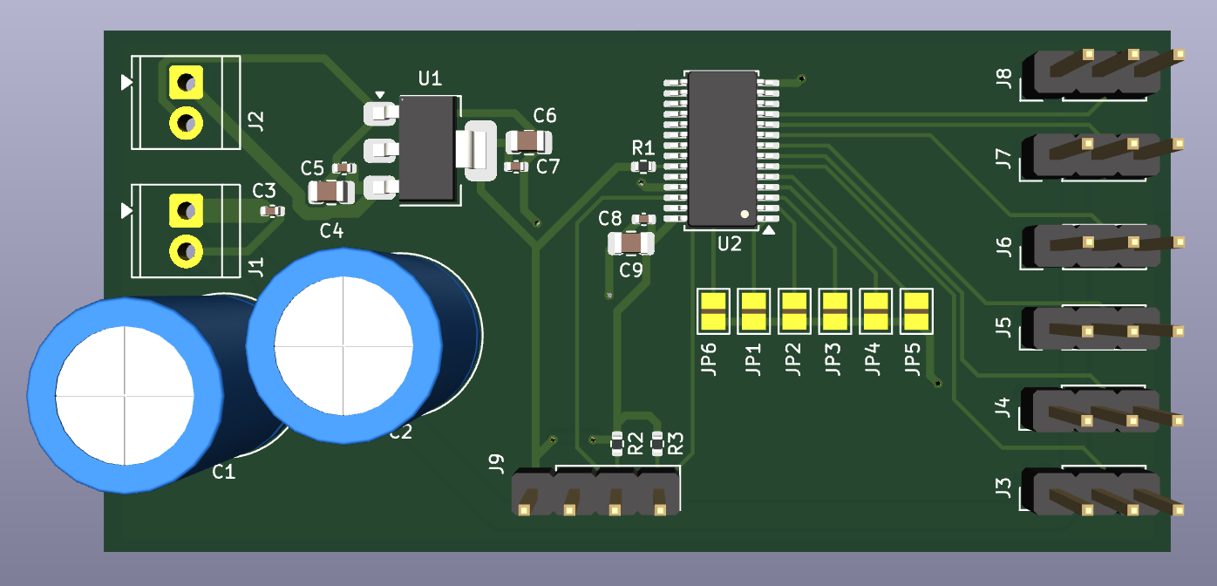
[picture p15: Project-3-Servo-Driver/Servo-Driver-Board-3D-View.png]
3D View


## Overview

The board separates the servo power rail (+VSERVO, 5–6V, high current) from
the logic rail (+3.3V, low current) to prevent servo switching transients
from disturbing the PCA9685 and I²C bus. A host microcontroller — such as
the STM32 on the SDMMC Logger board — sends PWM duty cycle commands over I²C,
and the PCA9685 generates the corresponding 50Hz servo control signals on its
output channels. The I²C header pinout matches the EMG Acquisition Board and
SDMMC Logger for direct cable connection across the system.

## Why PCA9685 Instead of an STM32

Generating 6 independent 50Hz PWM signals in firmware consumes 6 hardware
timer channels on a host MCU, leaving fewer resources for sensor reading,
gesture classification, and data logging running concurrently. The PCA9685
offloads all PWM generation to dedicated hardware over a single I²C
connection, freeing the host MCU entirely. It also allows the servo driver
to be replaced or reconfigured independently of the host firmware, and
supports up to 64 boards on one I²C bus via address pin configuration —
making the architecture extensible to more complex prosthetic hand designs
with more degrees of freedom.

## Design Notes

**Dual power rail architecture:** Two separate screw terminals feed the board.
J1 supplies +VSERVO (5–6V, rated for peak servo current) directly to the
servo headers and bulk capacitors. J2 supplies +5V to the AMS1117-3.3 LDO
which generates the 3.3V logic rail for the PCA9685. The rails are
intentionally separate — servo motors produce large current transients during
acceleration and stall, and coupling these onto the logic rail would cause
I²C communication errors and PWM glitches.

**Bulk capacitance on servo rail:** Two 1000µF electrolytic capacitors (C1,
C2) are placed immediately adjacent to J1 on the +VSERVO rail. These absorb
the inrush current when multiple servos move simultaneously and prevent the
supply voltage from drooping during peak load. Without them, a sudden
multi-servo movement would cause a voltage dip that could brown out the logic
rail through ground bounce. A 100nF ceramic capacitor (C3) provides
high-frequency decoupling in parallel.

**VSERVO trace width:** The +VSERVO rail and its GND return are routed at
1.5mm throughout the board. With 6 servos drawing up to 1A each at stall,
the rail must handle up to 6A peak. A 1.5mm trace on 1oz copper carries
approximately 2.5A with a 10°C temperature rise — the parallel GND return
path and copper pour keep the effective current capacity well above the
peak demand.

**PWM output channels:** The PCA9685 exposes 16 PWM channels (LED0–LED15).
This board uses LED0–LED5 for the six servo outputs, connected through
0.25mm signal traces to J3–J8. LED6–LED15 are left unconnected with
no-connect flags, available for future expansion to additional servo axes.

**Address selection:** Six solder jumpers (JP1–JP6) connect address pins
A0–A5 to GND. All jumpers are open by default — the PCA9685's internal
pull-downs hold the address pins low, setting the I²C address to 0x40.
Bridging any jumper hard-connects that address pin to GND, which is
electrically identical but noise-immune. If a second servo driver board
is added to the same I²C bus, bridge one jumper to assign address 0x41,
avoiding a bus conflict without any firmware changes to the first board.

**OE pin:** The active-low Output Enable pin (OE) is pulled high to +3.3V
through R1 (10kΩ), keeping all PWM outputs active by default. Pulling OE
low externally disables all outputs simultaneously — useful for a hardware
emergency stop without an I²C transaction.

**EXTCLK pin:** Tied to GND, disabling the external clock input and selecting
the PCA9685's internal 25MHz oscillator. No external crystal is required.

**Stackup rationale:** Signals and power are routed on F.Cu. B.Cu carries a
solid unbroken GND pour covering the entire board — no GND pour on F.Cu.
This gives every F.Cu trace a direct return path immediately beneath it,
which is the optimal configuration for a 2-layer board. A fragmented F.Cu
pour would create isolated copper islands requiring stitching vias and
inconsistent return paths under the PWM signal traces. Stitching vias connect
the board edge GND connections to the B.Cu plane.

## Servo Connector Pinout

Each of J3–J8 follows the standard servo connector pinout:

| Pin | Signal |
|---|---|
| 1 | GND |
| 2 | +VSERVO (5–6V) |
| 3 | PWM signal |

## I²C Interface

| J9 Pin | Signal |
|---|---|
| 1 | +3.3V |
| 2 | GND |
| 3 | SCL |
| 4 | SDA |

Default I²C address: **0x40** (all address jumpers open)

## Manufacturing

- 2-layer stackup: F.Cu (signal + power) / B.Cu (solid GND plane)
- 1.6mm FR4, standard 1oz copper
- Passed DRC with 0 violations, 0 unconnected nets
- Gerbers and drill files generated

## Part of

Smart Prosthetic Arm — Project 3 of 6

## Tools

- KiCad

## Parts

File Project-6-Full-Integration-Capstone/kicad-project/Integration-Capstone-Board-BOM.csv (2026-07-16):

Id | Designator | Footprint | Quantity | Designation | Supplier and ref
1 | J6,J8,J4 | PinHeader_1x04_P2.54mm_Vertical | 3 | Conn_01x04
2 | C3,C1 | C_0805_2012Metric | 2 | 10µF
3 | R4,R3,R1,R5,R6,R2 | R_0402_1005Metric | 6 | 10kΩ
4 | C5 | C_Radial_D8.0mm_H11.5mm_P3.50mm | 1 | 100µF
5 | R10,R11,R9 | R_0402_1005Metric | 3 | 330Ω
6 | D3,D2,D1 | LED_0402_1005Metric | 3 | LED
7 | U3 | SOT-23-6 | 1 | USBLC6-2SC6
8 | C10,C12,C14,C8,C11,C4,C9,C2 | C_0402_1005Metric | 8 | 100nF
9 | C6,C7 | C_0402_1005Metric | 2 | 12pF
10 | C13 | C_0402_1005Metric | 1 | 1µF
11 | U2 | LQFP-64_10x10mm_P0.5mm | 1 | STM32F411RETx
12 | R7,R8 | R_0402_1005Metric | 2 | 22Ω
13 | J2,J1 | TerminalBlock_TE_282834-2_1x02_P2.54mm_Horizontal | 2 | Conn_01x02
14 | J3 | PinHeader_1x02_P2.54mm_Vertical | 1 | Conn_01x02
15 | U1 | SOT-223-3_TabPin2 | 1 | AMS1117-3.3
16 | J7 | PinHeader_1x12_P2.54mm_Vertical | 1 | Conn_01x12
17 | Y1 | Crystal_SMD_2520-4Pin_2.5x2.0mm | 1 | Crystal
18 | J9 | USB_Micro-B_Amphenol_10118194_Horizontal | 1 | USB_B_Micro
19 | SW1 | SW_SPST_PTS645Sx43SMTR92 | 1 | SW_SPST
20 | J5 | PinHeader_1x07_P2.54mm_Vertical | 1 | Conn_01x07

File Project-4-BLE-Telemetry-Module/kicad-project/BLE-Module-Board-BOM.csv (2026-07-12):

Id | Designator | Footprint | Quantity | Designation | Supplier and ref
1 | R2,R3 | R_0402_1005Metric | 2 | 22Ω
2 | U2 | Nordic_AQFN-73-1EP_7x7mm_P0.5mm | 1 | nRF52840
3 | C18 | C_0402_1005Metric | 1 | 1.8pF
4 | C17,C15,C16,C9 | C_0805_2012Metric | 4 | 4.7µF
5 | C2,C8,C14,C7,C11,C12,C10,C5,C6,C13,C4 | C_0402_1005Metric | 11 | 100nF
6 | U1 | SOT-23-5 | 1 | XC6210B332MR
7 | C1,C3 | C_0805_2012Metric | 2 | 10µF
8 | Y2 | Crystal_SMD_3215-2Pin_3.2x1.5mm | 1 | Crystal 32.768kHz
9 | F1 | Fuse_1812_4532Metric | 1 | Polyfuse
10 | J_ANT1 | PinHeader_1x01_P2.54mm_Vertical | 1 | Conn_01x01
11 | J3 | PinHeader_1x12_P2.54mm_Vertical | 1 | Conn_01x12
12 | C19 | C_0402_1005Metric | 1 | 1.5pF
13 | SW1 | SW_SPST_PTS645Sx43SMTR92 | 1 | SW_SPST
14 | C20,C21 | C_0402_1005Metric | 2 | 8pF
15 | D1 | SOT-23 | 1 | BAT54S
16 | C22,C23 | C_0402_1005Metric | 2 | 12pF
17 | R4,R5,R1 | R_0402_1005Metric | 3 | 10kΩ
18 | J2 | PinHeader_1x02_P2.54mm_Vertical | 1 | Conn_01x02
19 | Y1 | Crystal_SMD_2520-4Pin_2.5x2.0mm | 1 | Crystal 32MHz
20 | U3 | SOT-23-6 | 1 | USBLC6-2SC6
21 | J1 | USB_Micro-B_Amphenol_10118194_Horizontal | 1 | USB_B_Micro
22 | L1 | L_0402_1005Metric | 1 | 3.9nH

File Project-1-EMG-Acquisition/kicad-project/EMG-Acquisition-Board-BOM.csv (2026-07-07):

Id | Designator | Footprint | Quantity | Designation | Supplier and ref
1 | R5,R12,R9,R18,R11,R17,R10,R8 | R_0402_1005Metric | 8 | 10kΩ
2 | C11,C4,C1,C6,C10,C12,C8,C9 | C_0402_1005Metric | 8 | 100nF
3 | R1,R2 | R_0402_1005Metric | 2 | 100kΩ
4 | U4 | SOIC-8_3.9x4.9mm_P1.27mm | 1 | TLV2372
5 | R16,R15 | R_0402_1005Metric | 2 | 3.3kΩ
6 | R4,R7,R3,R6 | R_0402_1005Metric | 4 | 1MΩ
7 | Rg1,Rg2 | R_0402_1005Metric | 2 | 1kΩ
8 | C2,C7,C3,C5,C13 | C_0805_2012Metric | 5 | 10µF
9 | R13,R14 | R_0402_1005Metric | 2 | 30kΩ
10 | U5 | TSSOP-10_3x3mm_P0.5mm | 1 | ADS1115IDGS
11 | U2,U3 | WSON-8-1EP_3x3mm_P0.5mm_EP1.45x2.4mm | 2 | INA333xxDRG
12 | J1,J2 | PinHeader_1x02_P2.54mm_Vertical | 2 | Conn_01x02
13 | U1 | SOT-353_SC-70-5 | 1 | TLV6001DCK
14 | J3 | PinHeader_1x04_P2.54mm_Vertical | 1 | Conn_01x04

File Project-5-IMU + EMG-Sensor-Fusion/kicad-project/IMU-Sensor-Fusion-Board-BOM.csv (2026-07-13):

Id | Designator | Footprint | Quantity | Designation | Supplier and ref
1 | R2,R4,R3,R1 | R_0402_1005Metric | 4 | 10kΩ
2 | C3,C2,C4,C5 | C_0402_1005Metric | 4 | 100nF
3 | J3 | PinHeader_1x04_P2.54mm_Vertical | 1 | Conn_01x04
4 | C6 | C_0402_1005Metric | 1 | 1µF
5 | C1 | C_0805_2012Metric | 1 | 10µF
6 | U1 | IIM42352 | 1 | ICM-42688-P
7 | J1 | PinHeader_1x02_P2.54mm_Vertical | 1 | Conn_01x02
8 | J2 | PinHeader_1x07_P2.54mm_Vertical | 1 | Conn_01x07

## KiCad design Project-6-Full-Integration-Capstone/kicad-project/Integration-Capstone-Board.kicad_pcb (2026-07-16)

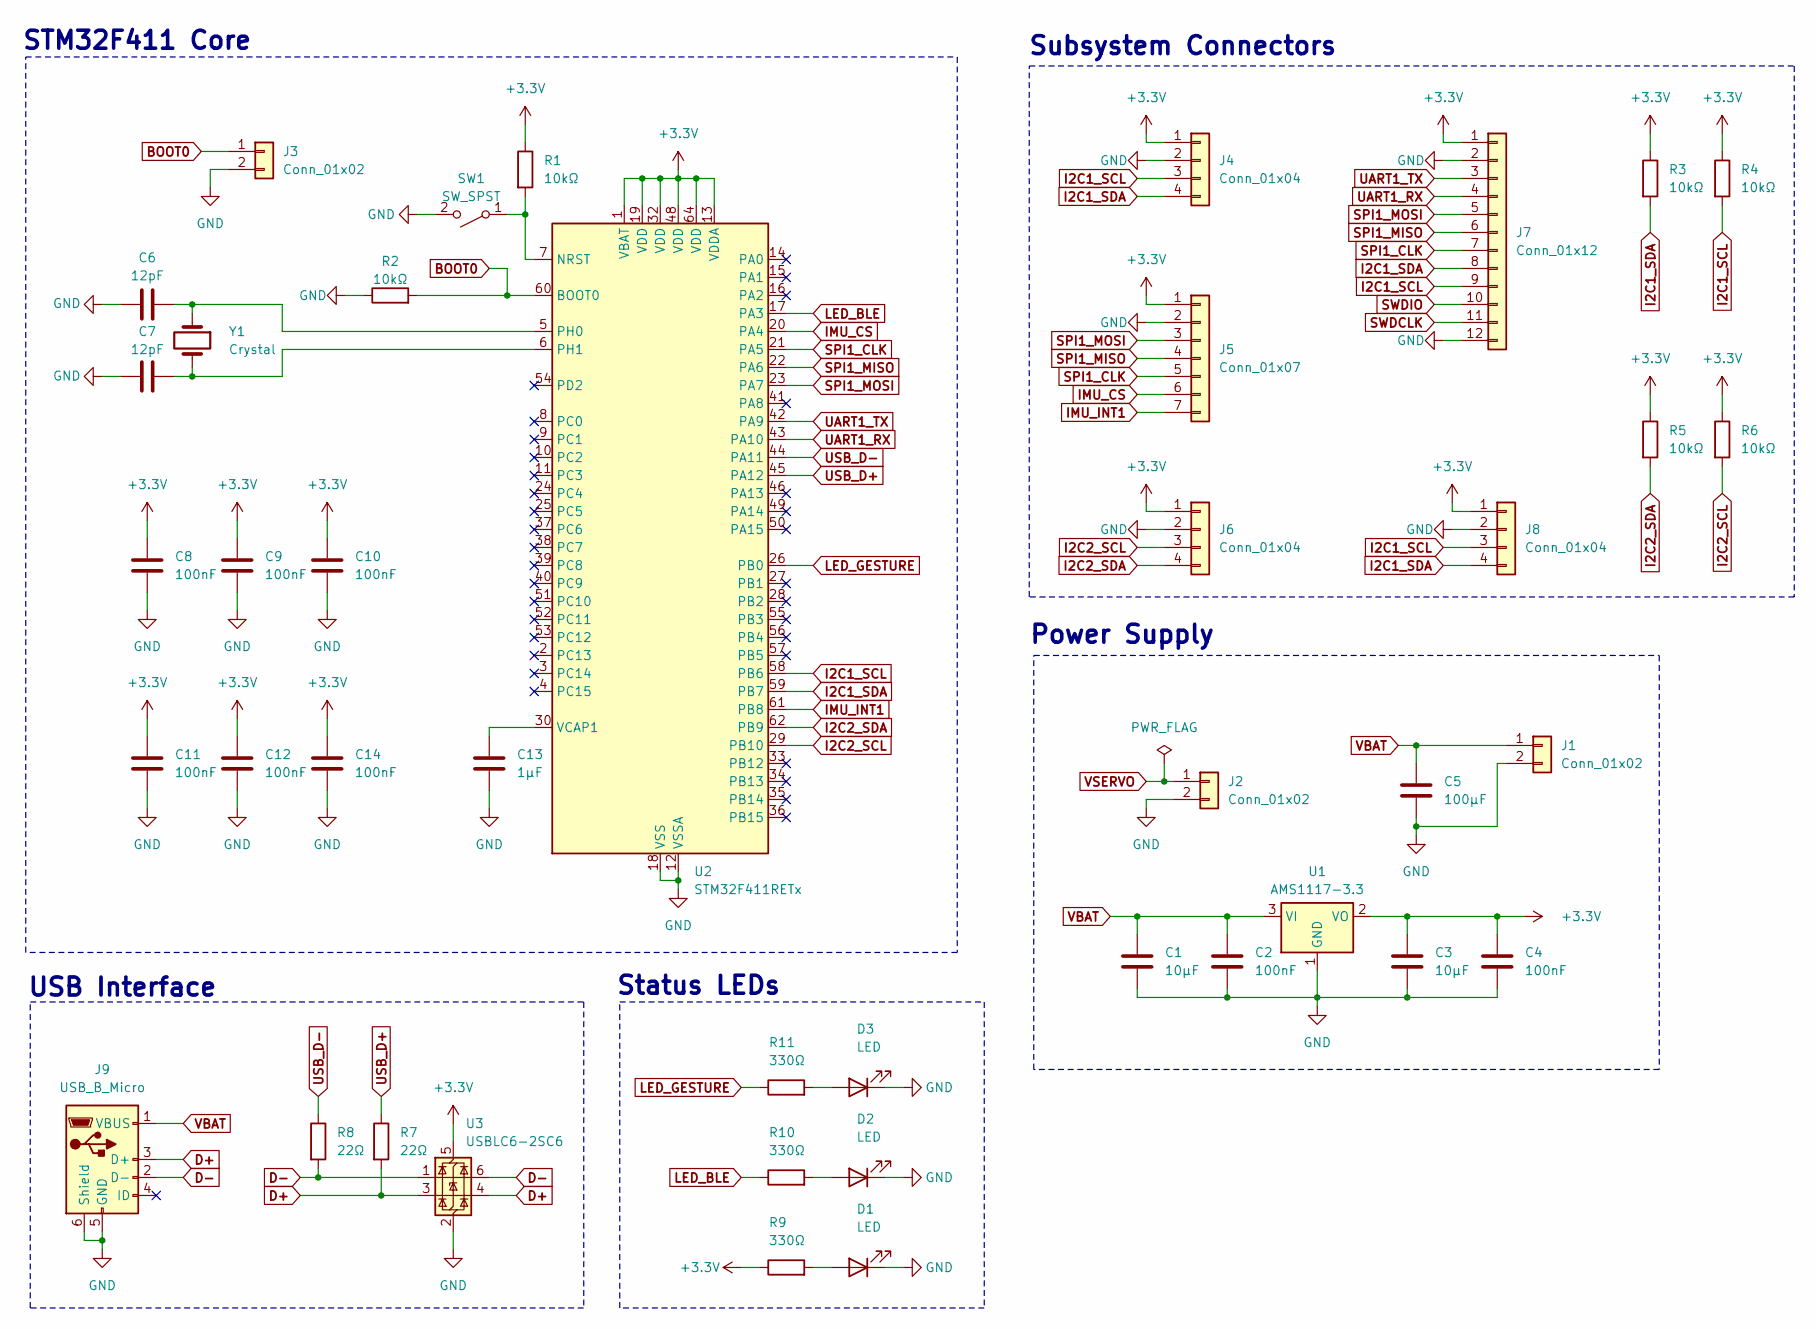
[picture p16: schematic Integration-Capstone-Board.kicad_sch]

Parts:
C1, C3: 10µF; C_0805_2012Metric
C2, C4, C8, C9, C10, C11, C12, C14: 100nF; C_0402_1005Metric
C5: 100µF; C_Radial_D8.0mm_H11.5mm_P3.50mm
C6, C7: 12pF; C_0402_1005Metric
C13: 1µF; C_0402_1005Metric
D1, D2, D3: LED; LED_0402_1005Metric
J1, J2: Conn_01x02; TerminalBlock_TE_282834-2_1x02_P2.54mm_Horizontal
J3: Conn_01x02; PinHeader_1x02_P2.54mm_Vertical
J4, J6, J8: Conn_01x04; PinHeader_1x04_P2.54mm_Vertical
J5: Conn_01x07; PinHeader_1x07_P2.54mm_Vertical
J7: Conn_01x12; PinHeader_1x12_P2.54mm_Vertical
J9: USB_B_Micro; USB_Micro-B_Amphenol_10118194_Horizontal
R1, R2, R3, R4, R5, R6: 10kΩ; R_0402_1005Metric
R7, R8: 22Ω; R_0402_1005Metric
R9, R10, R11: 330Ω; R_0402_1005Metric
SW1: SW_SPST; SW_SPST_PTS645Sx43SMTR92
U1: AMS1117-3.3; SOT-223-3_TabPin2
U2: STM32F411RETx; LQFP-64_10x10mm_P0.5mm
U3: USBLC6-2SC6; SOT-23-6
Y1: Crystal; Crystal_SMD_2520-4Pin_2.5x2.0mm

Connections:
+3.3V: C3.1, C4.1, C8.1, C9.1, C10.1, C11.1, C12.1, C14.1, J4.1, J5.1, J6.1, J7.1, J8.1, R1.1, R3.1, R4.1, R5.1, R6.1, R9.1, U1.2 (VO), U2.1 (VBAT), U2.13 (VDDA), U2.19 (VDD), U2.32 (VDD), U2.48 (VDD), U2.64 (VDD), U3.5 (VBUS)
BOOT0: J3.1, R2.2, U2.60 (BOOT0)
D+: J9.3 (D+), R7.2, U3.3 (I/O2), U3.4 (I/O2)
D-: J9.2 (D-), R8.2, U3.1 (I/O1), U3.6 (I/O1)
GND: C1.2, C2.2, C3.2, C4.2, C5.2, C6.1, C7.1, C8.2, C9.2, C10.2, C11.2, C12.2, C13.2, C14.2, D1.1 (K), D2.1 (K), D3.1 (K), J1.2, J2.2, J3.2, J4.2, J5.2, J6.2, J7.2, J7.12, J8.2, J9.5 (GND), J9.6 (Shield), R2.1, SW1.2 (B), U1.1 (GND), U2.12 (VSSA), U2.18 (VSS), U2.31 (VSS), U2.47 (VSS), U2.63 (VSS), U3.2 (GND), Y1.3, Y1.4
I2C1_SCL: J4.3, J7.9, J8.3, R4.2, U2.58 (PB6)
I2C1_SDA: J4.4, J7.8, J8.4, R3.2, U2.59 (PB7)
I2C2_SCL: J6.3, R6.2, U2.29 (PB10)
I2C2_SDA: J6.4, R5.2, U2.62 (PB9)
IMU_CS: J5.6, U2.20 (PA4)
IMU_INT1: J5.7, U2.61 (PB8)
LED_BLE: R10.1, U2.17 (PA3)
LED_GESTURE: R11.1, U2.26 (PB0)
unnamed: D1.2 (A), R9.2
unnamed: D2.2 (A), R10.2
unnamed: D3.2 (A), R11.2
unnamed: R1.2, SW1.1 (A), U2.7 (NRST)
unnamed: C6.2, U2.5 (PH0), Y1.1
unnamed: C7.2, U2.6 (PH1), Y1.2
unnamed: C13.1, U2.30 (VCAP1)
SPI1_CLK: J5.5, J7.7, U2.21 (PA5)
SPI1_MISO: J5.4, J7.6, U2.22 (PA6)
SPI1_MOSI: J5.3, J7.5, U2.23 (PA7)
SWDCLK: J7.11
SWDIO: J7.10
UART1_RX: J7.4, U2.43 (PA10)
UART1_TX: J7.3, U2.42 (PA9)
USB_D+: R7.1, U2.45 (PA12)
USB_D-: R8.1, U2.44 (PA11)
VBAT: C1.1, C2.1, C5.1, J1.1, J9.1 (VBUS), U1.3 (VI)
VSERVO: J2.1

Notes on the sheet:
STM32F411 Core
Status LEDs
Subsystem Connectors
Power Supply
USB Interface

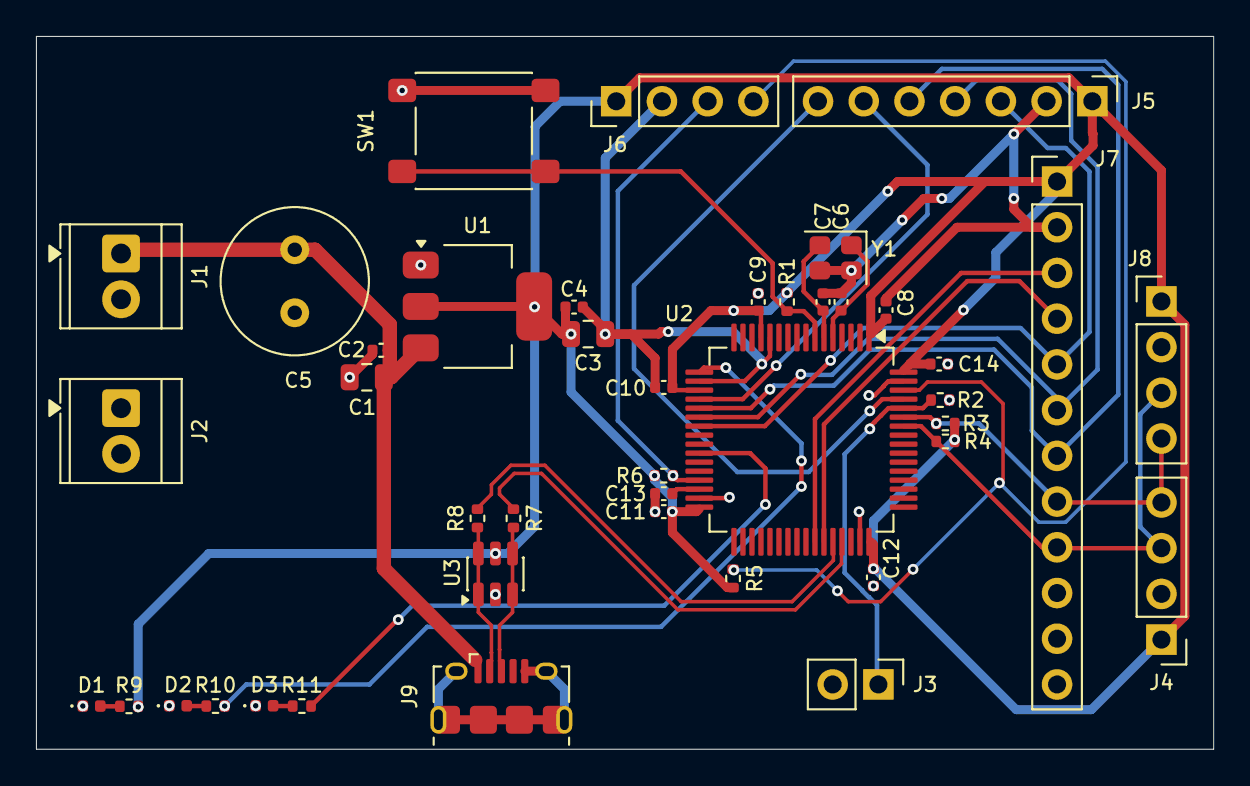
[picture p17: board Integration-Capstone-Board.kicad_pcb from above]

Board: 2 copper layers, 65.4 x 39.6 mm, 42 parts (0 on the bottom side), 28 nets.

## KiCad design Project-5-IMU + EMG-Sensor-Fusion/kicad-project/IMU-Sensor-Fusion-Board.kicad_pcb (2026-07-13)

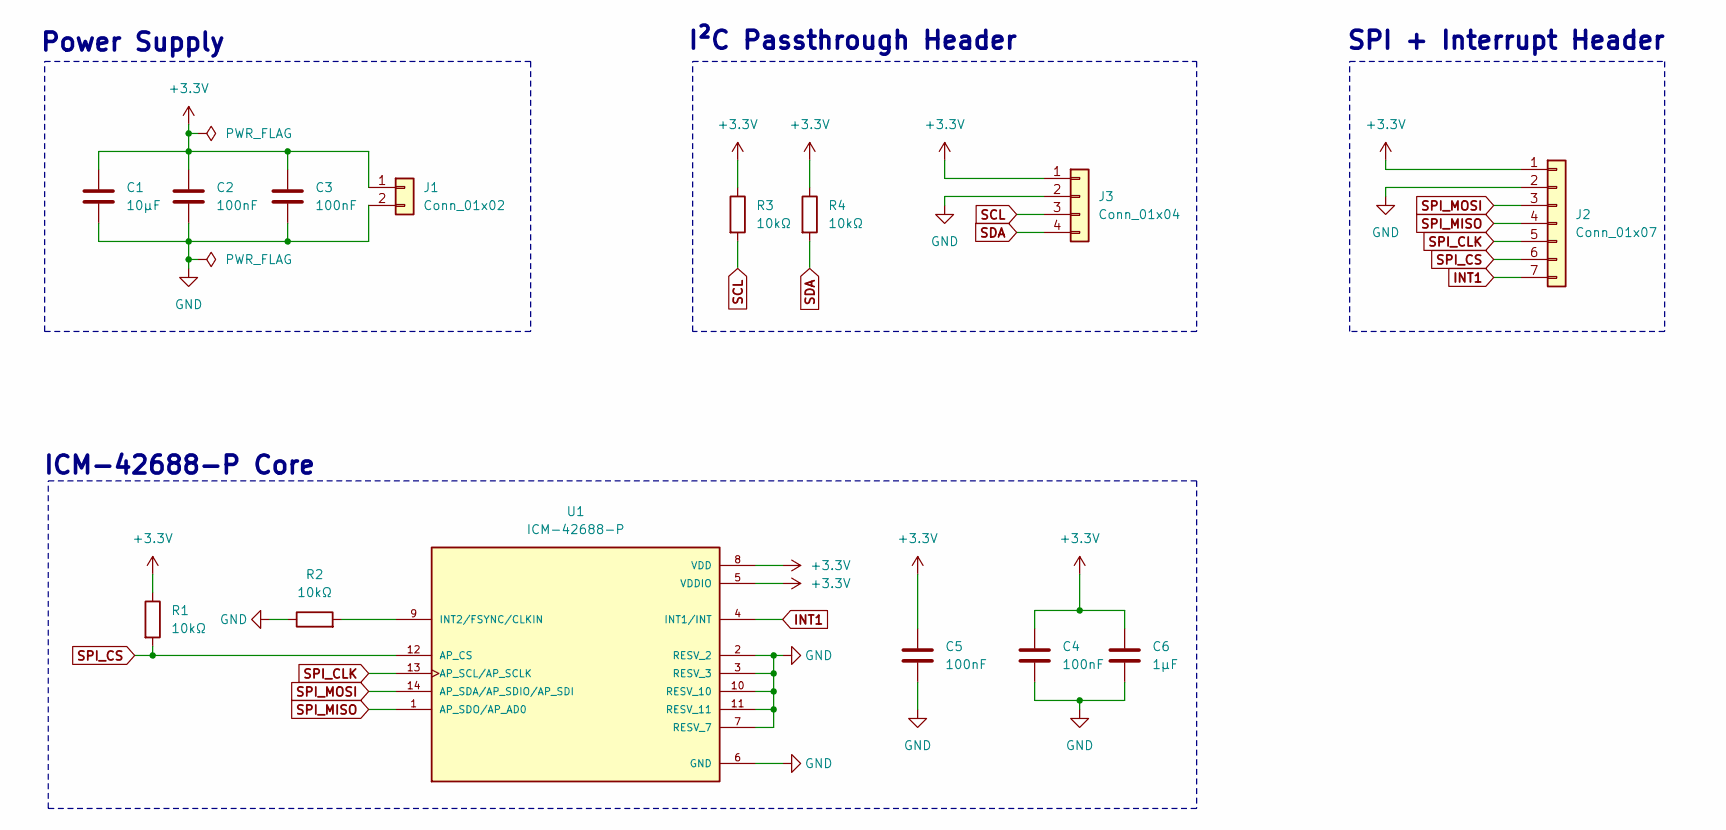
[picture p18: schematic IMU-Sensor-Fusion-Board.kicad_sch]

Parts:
C1: 10µF; C_0805_2012Metric
C2, C3, C4, C5: 100nF; C_0402_1005Metric
C6: 1µF; C_0402_1005Metric
J1: Conn_01x02; PinHeader_1x02_P2.54mm_Vertical
J2: Conn_01x07; PinHeader_1x07_P2.54mm_Vertical
J3: Conn_01x04; PinHeader_1x04_P2.54mm_Vertical
R1, R2, R3, R4: 10kΩ; R_0402_1005Metric
U1: ICM-42688-P; IIM42352; PARTREV 1.2

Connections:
+3.3V: C1.1, C2.1, C3.1, C4.1, C5.1, C6.1, J1.1, J2.1, J3.1, R1.1, R3.1, R4.1, U1.5 (VDDIO), U1.8 (VDD)
GND: C1.2, C2.2, C3.2, C4.2, C5.2, C6.2, J1.2, J2.2, J3.2, R2.1, U1.2 (RESV_2), U1.3 (RESV_3), U1.6 (GND), U1.7 (RESV_7), U1.10 (RESV_10), U1.11 (RESV_11)
INT1: J2.7, U1.4 (INT1/INT)
unnamed: R2.2, U1.9 (INT2/FSYNC/CLKIN)
SCL: J3.3, R3.2
SDA: J3.4, R4.2
SPI_CLK: J2.5, U1.13 (AP_SCL/AP_SCLK)
SPI_CS: J2.6, R1.2, U1.12 (AP_CS)
SPI_MISO: J2.4, U1.1 (AP_SDO/AP_AD0)
SPI_MOSI: J2.3, U1.14 (AP_SDA/AP_SDIO/AP_SDI)

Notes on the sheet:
Power Supply
I²C Passthrough Header
ICM-42688-P Core
SPI + Interrupt Header

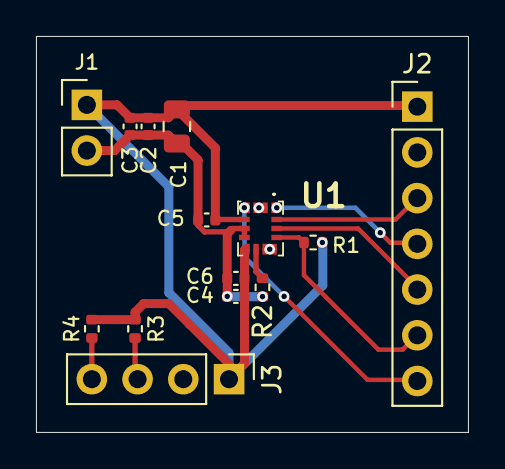
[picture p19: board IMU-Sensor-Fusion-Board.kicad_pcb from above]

Board: 2 copper layers, 24.0 x 22.0 mm, 14 parts (0 on the bottom side), 10 nets.

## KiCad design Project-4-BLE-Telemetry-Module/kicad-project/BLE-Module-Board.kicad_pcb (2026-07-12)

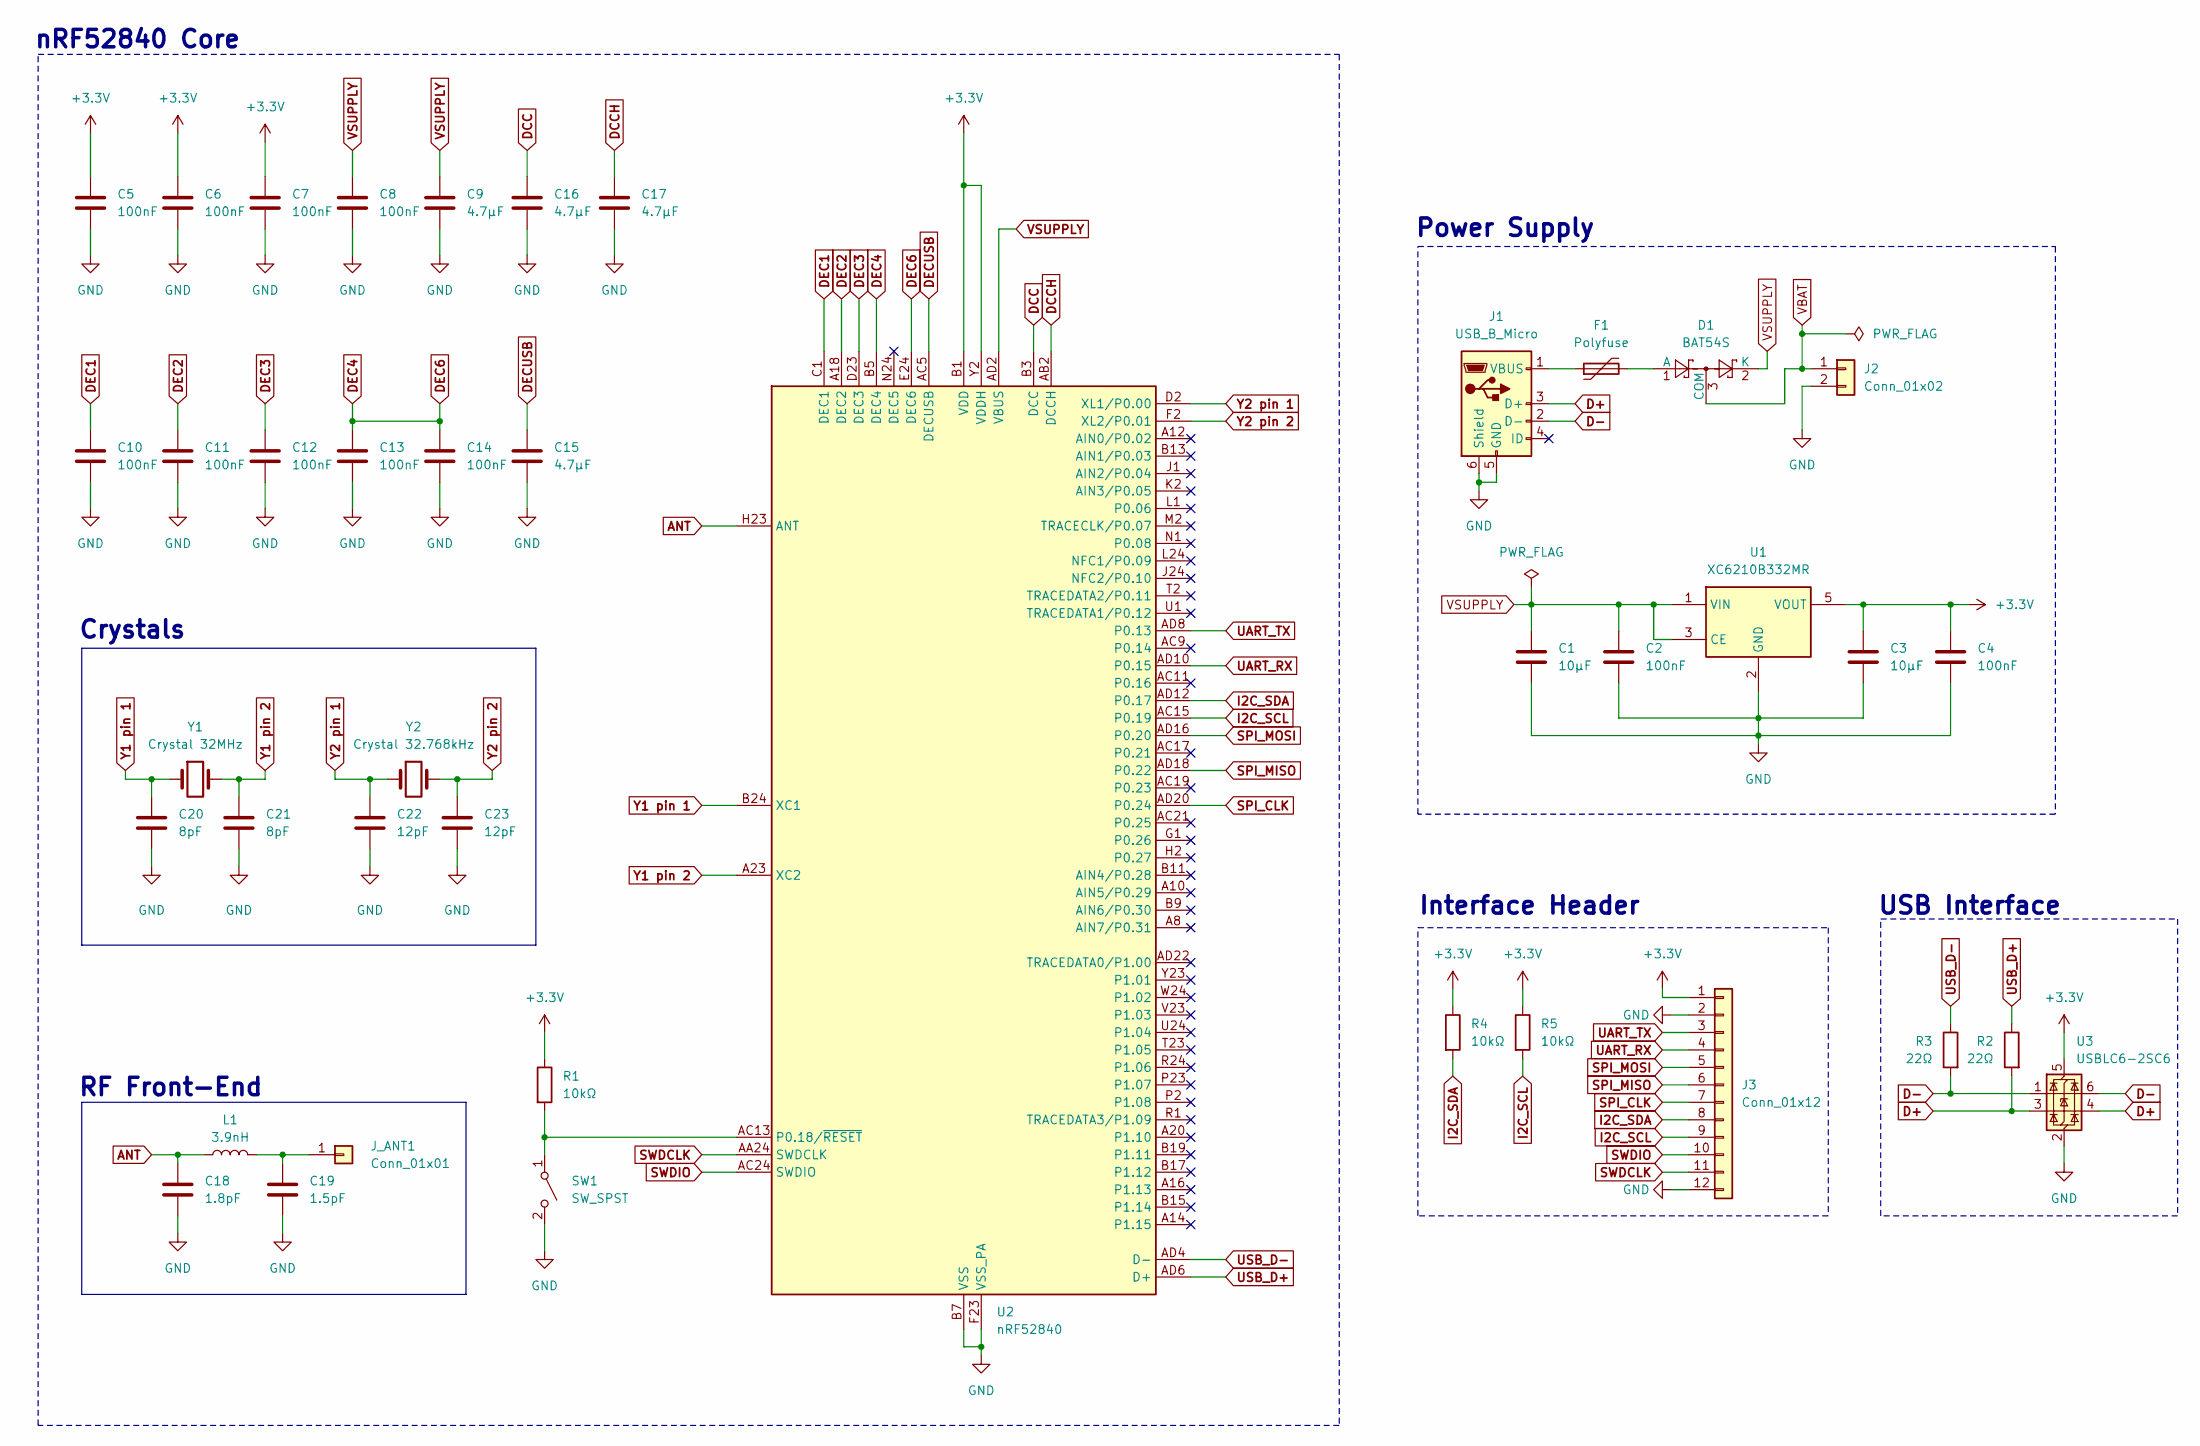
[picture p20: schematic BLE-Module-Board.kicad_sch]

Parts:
C1, C3: 10µF; C_0805_2012Metric
C2, C4, C5, C6, C7, C8, C10, C11, C12, C13, C14: 100nF; C_0402_1005Metric
C9, C15, C16, C17: 4.7µF; C_0805_2012Metric
C18: 1.8pF; C_0402_1005Metric
C19: 1.5pF; C_0402_1005Metric
C20, C21: 8pF; C_0402_1005Metric
C22, C23: 12pF; C_0402_1005Metric
D1: BAT54S; SOT-23
F1: Polyfuse; Fuse_1812_4532Metric
J1: USB_B_Micro; USB_Micro-B_Amphenol_10118194_Horizontal
J2: Conn_01x02; PinHeader_1x02_P2.54mm_Vertical
J3: Conn_01x12; PinHeader_1x12_P2.54mm_Vertical
J_ANT1: Conn_01x01; PinHeader_1x01_P2.54mm_Vertical
L1: 3.9nH; L_0402_1005Metric
R1, R4, R5: 10kΩ; R_0402_1005Metric
R2, R3: 22Ω; R_0402_1005Metric
SW1: SW_SPST; SW_SPST_PTS645Sx43SMTR92
U1: XC6210B332MR; SOT-23-5
U2: nRF52840; Nordic_AQFN-73-1EP_7x7mm_P0.5mm
U3: USBLC6-2SC6; SOT-23-6
Y1: Crystal 32MHz; Crystal_SMD_2520-4Pin_2.5x2.0mm
Y2: Crystal 32.768kHz; Crystal_SMD_3215-2Pin_3.2x1.5mm

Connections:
+3.3V: C3.1, C4.1, C5.1, C6.1, C7.1, J3.1, R1.1, R4.1, R5.1, U1.5 (VOUT), U2.A22 (VDD), U2.AD14 (VDD), U2.AD23 (VDD), U2.B1 (VDD), U2.W1 (VDD), U2.Y2 (VDDH), U3.5 (VBUS)
ANT: C18.1, L1.1, U2.H23 (ANT)
D+: J1.3 (D+), R2.2, U3.3 (I/O2), U3.4 (I/O2)
D-: J1.2 (D-), R3.2, U3.1 (I/O1), U3.6 (I/O1)
DCC: C16.1, U2.B3 (DCC)
DCCH: C17.1, U2.AB2 (DCCH)
DEC1: C10.1, U2.C1 (DEC1)
DEC2: C11.1, U2.A18 (DEC2)
DEC3: C12.1, U2.D23 (DEC3)
DEC4: C13.1, C14.1, U2.B5 (DEC4), U2.E24 (DEC6)
DECUSB: C15.1, U2.AC5 (DECUSB)
GND: C1.2, C2.2, C3.2, C4.2, C5.2, C6.2, C7.2, C8.2, C9.2, C10.2, C11.2, C12.2, C13.2, C14.2, C15.2, C16.2, C17.2, C18.2, C19.2, C20.2, C21.2, C22.2, C23.2, J1.5 (GND), J1.6 (Shield), J2.2, J3.2, J3.12, SW1.2 (B), U1.2 (GND), U2.B7 (VSS), U2.EP (VSS), U2.F23 (VSS_PA), U3.2 (GND), Y1.3, Y1.4
I2C_SCL: J3.9, R5.2, U2.AC15 (P0.19)
I2C_SDA: J3.8, R4.2, U2.AD12 (P0.17)
unnamed: D1.1 (A), F1.2
unnamed: F1.1, J1.1 (VBUS)
unnamed: C19.1, J_ANT1.1, L1.2
unnamed: R1.2, SW1.1 (A), U2.AC13 (P0.18/~RESET)
SPI_CLK: J3.7, U2.AD20 (P0.24)
SPI_MISO: J3.6, U2.AD18 (P0.22)
SPI_MOSI: J3.5, U2.AD16 (P0.20)
SWDCLK: J3.11, U2.AA24 (SWDCLK)
SWDIO: J3.10, U2.AC24 (SWDIO)
UART_RX: J3.4, U2.AD10 (P0.15)
UART_TX: J3.3, U2.AD8 (P0.13)
USB_D+: R2.1, U2.AD6 (D+)
USB_D-: R3.1, U2.AD4 (D-)
VBAT: D1.3 (COM), J2.1
VSUPPLY: C1.1, C2.1, C8.1, C9.1, D1.2 (K), U1.1 (VIN), U1.3 (CE), U2.AD2 (VBUS)
Y1 pin 1: C20.1, U2.B24 (XC1), Y1.1
Y1 pin 2: C21.1, U2.A23 (XC2), Y1.2
Y2 pin 1: C22.1, U2.D2 (XL1/P0.00), Y2.1
Y2 pin 2: C23.1, U2.F2 (XL2/P0.01), Y2.2

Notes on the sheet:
USB Interface
RF Front-End
Crystals
Power Supply
Interface Header
nRF52840 Core

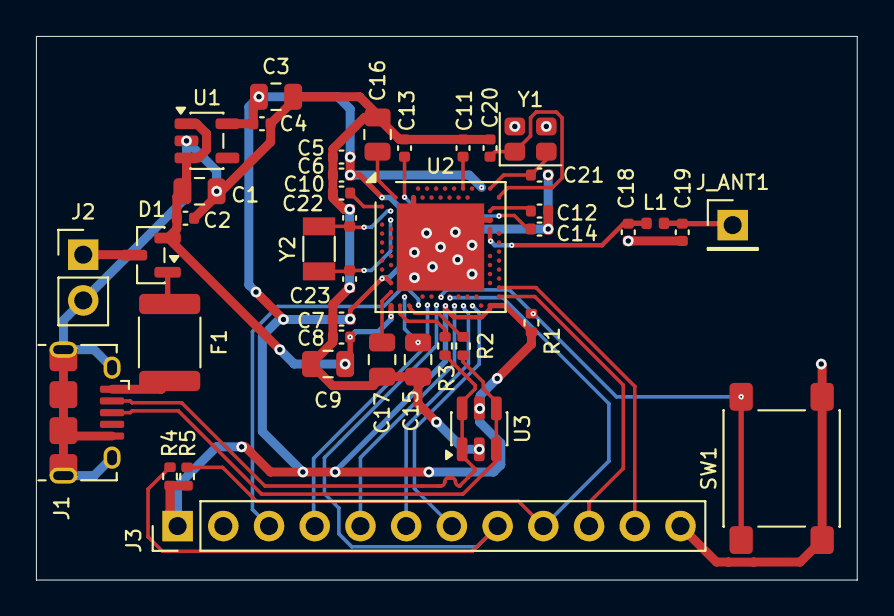
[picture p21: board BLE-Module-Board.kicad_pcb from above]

Board: 2 copper layers, 45.6 x 30.2 mm, 41 parts (0 on the bottom side), 33 nets.

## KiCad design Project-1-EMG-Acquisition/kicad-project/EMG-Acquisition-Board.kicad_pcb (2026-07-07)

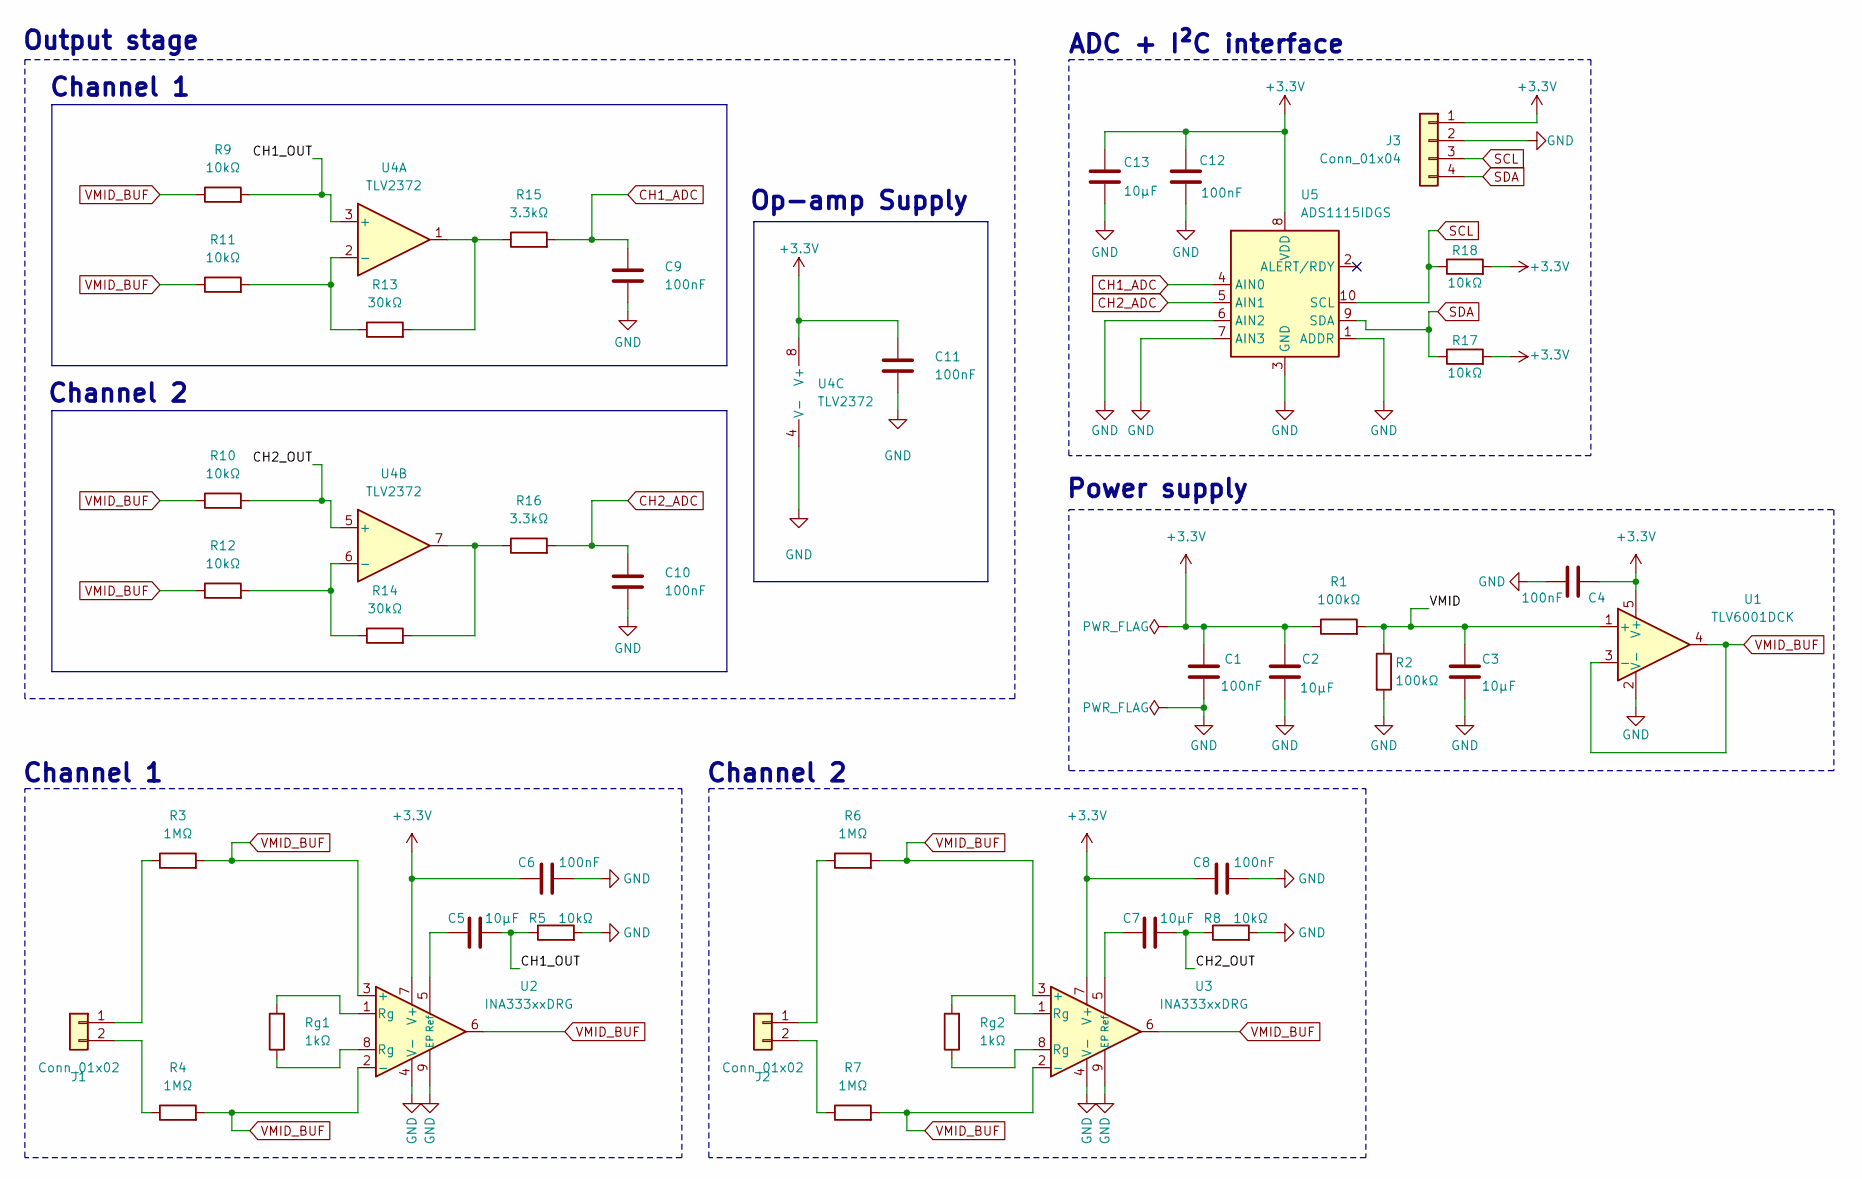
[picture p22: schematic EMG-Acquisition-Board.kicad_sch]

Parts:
C1, C4, C6, C8, C9, C10, C11, C12: 100nF; C_0402_1005Metric
C2, C3, C5, C7, C13: 10µF; C_0805_2012Metric
J1, J2: Conn_01x02; PinHeader_1x02_P2.54mm_Vertical
J3: Conn_01x04; PinHeader_1x04_P2.54mm_Vertical
R1, R2: 100kΩ; R_0402_1005Metric
R3, R4, R6, R7: 1MΩ; R_0402_1005Metric
R5, R8, R9, R10, R11, R12, R17, R18: 10kΩ; R_0402_1005Metric
R13, R14: 30kΩ; R_0402_1005Metric
R15, R16: 3.3kΩ; R_0402_1005Metric
Rg1, Rg2: 1kΩ; R_0402_1005Metric
U1: TLV6001DCK; SOT-353_SC-70-5
U2, U3: INA333xxDRG; WSON-8-1EP_3x3mm_P0.5mm_EP1.45x2.4mm
U4: TLV2372; SOIC-8_3.9x4.9mm_P1.27mm
U5: ADS1115IDGS; TSSOP-10_3x3mm_P0.5mm

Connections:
+3.3V: C1.1, C2.1, C4.1, C6.1, C8.1, C11.1, C12.1, C13.1, J3.1, R1.1, R17.2, R18.2, U1.5 (V+), U2.7 (V+), U3.7 (V+), U4.8 (V+), U5.8 (VDD)
/CH1_OUT: C5.2, R5.1, R9.2, U4.3 (+)
/CH2_OUT: C7.2, R8.1, R10.2, U4.5 (+)
/VMID: C3.1, R1.2, R2.1, U1.1 (+)
CH1_ADC: C9.1, R15.2, U5.4 (AIN0)
CH2_ADC: C10.1, R16.2, U5.5 (AIN1)
GND: C1.2, C2.2, C3.2, C4.2, C6.2, C8.2, C9.2, C10.2, C11.2, C12.2, C13.2, J3.2, R2.2, R5.2, R8.2, U1.2 (V-), U2.4 (V-), U2.9 (EP), U3.4 (V-), U3.9 (EP), U4.4 (V-), U5.1 (ADDR), U5.3 (GND), U5.6 (AIN2), U5.7 (AIN3)
unnamed: J1.1, R3.1
unnamed: J1.2, R4.1
unnamed: J2.1, R6.1
unnamed: J2.2, R7.1
unnamed: R13.2, R15.1, U4.1
unnamed: R14.2, R16.1, U4.7
unnamed: Rg1.1, U2.8 (Rg)
unnamed: Rg1.2, U2.1 (Rg)
unnamed: Rg2.1, U3.8 (Rg)
unnamed: Rg2.2, U3.1 (Rg)
unnamed: C5.1, U2.5 (Ref)
unnamed: C7.1, U3.5 (Ref)
unnamed: R11.2, R13.1, U4.2 (-)
unnamed: R12.2, R14.1, U4.6 (-)
SCL: J3.3, R18.1, U5.10 (SCL)
SDA: J3.4, R17.1, U5.9 (SDA)
VMID_BUF: R3.2, R4.2, R6.2, R7.2, R9.1, R10.1, R11.1, R12.1, U1.3 (-), U1.4, U2.2 (-), U2.3 (+), U2.6, U3.2 (-), U3.3 (+), U3.6

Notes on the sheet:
Power supply
ADC + I²C interface
Op-amp Supply
Output stage
Channel 2
Channel 1

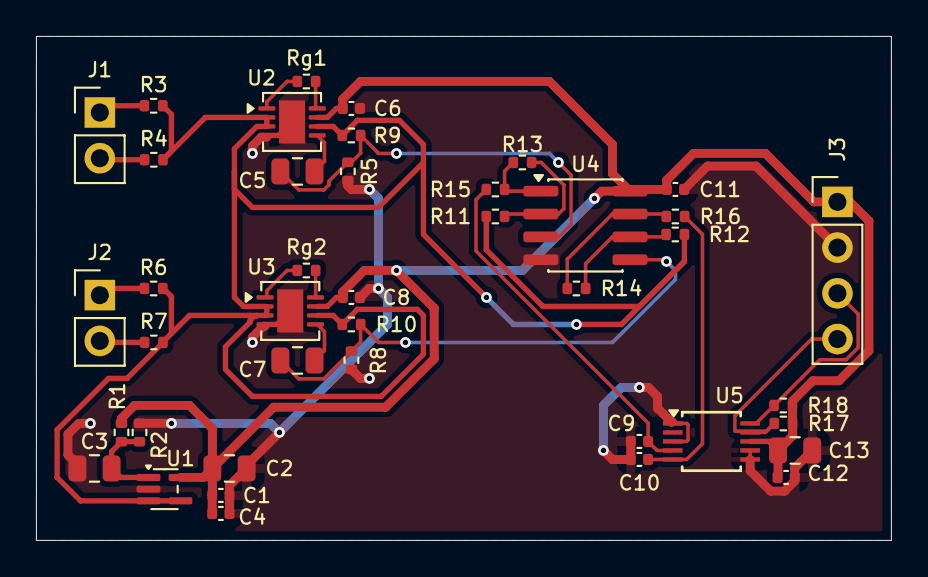
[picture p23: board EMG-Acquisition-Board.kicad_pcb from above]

Board: 2 copper layers, 47.5 x 28.0 mm, 41 parts (0 on the bottom side), 24 nets.

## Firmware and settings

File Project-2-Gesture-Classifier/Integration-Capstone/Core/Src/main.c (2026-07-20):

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
/* Includes ------------------------------------------------------------------*/
#include "main.h"
#include "usb_device.h"

/* USER CODE BEGIN Includes */
#include "emg.h"
#include "imu.h"
#include "classifier.h"
#include "servo.h"
#include "ble.h"
/* USER CODE END Includes */

I2C_HandleTypeDef hi2c1;
I2C_HandleTypeDef hi2c2;

SPI_HandleTypeDef hspi1;

UART_HandleTypeDef huart1;

void SystemClock_Config(void);
static void MX_GPIO_Init(void);
static void MX_I2C1_Init(void);
static void MX_I2C2_Init(void);
static void MX_SPI1_Init(void);
static void MX_USART1_UART_Init(void);
/**
  * @brief  The application entry point.
  * @retval int
  */
int main(void)
{

  /* MCU Configuration--------------------------------------------------------*/

  /* Reset of all peripherals, Initializes the Flash interface and the Systick. */
  HAL_Init();

  /* Configure the system clock */
  SystemClock_Config();

  /* Initialize all configured peripherals */
  MX_GPIO_Init();
  MX_I2C1_Init();
  MX_I2C2_Init();
  MX_SPI1_Init();
  MX_USART1_UART_Init();
  MX_USB_DEVICE_Init();
  /* USER CODE BEGIN 2 */
  EMG_Init(&hi2c1);
  IMU_Init(&hspi1);
  Servo_Init(&hi2c1);
  BLE_Init(&huart1);
  /* USER CODE END 2 */

  /* Infinite loop */
  /* USER CODE BEGIN WHILE */
  int16_t ch1_buf[EMG_WINDOW_SIZE];
  int16_t ch2_buf[EMG_WINDOW_SIZE];
  EMGFeatures features;
  IMUData imu_data;
  Gesture gesture;

  while (1) {
      EMG_CollectWindow(0, ch1_buf, EMG_WINDOW_SIZE);
      EMG_CollectWindow(1, ch2_buf, EMG_WINDOW_SIZE);
      EMG_ComputeFeatures(ch1_buf, ch2_buf, EMG_WINDOW_SIZE, &features);
      IMU_Read(&imu_data);
      gesture = Classifier_Run(&features, &imu_data);
      Servo_SetGesture(gesture);
      BLE_SendTelemetry(gesture, &features, &imu_data);

      HAL_GPIO_TogglePin(GPIOB, GPIO_PIN_0);
    /* USER CODE END WHILE */

    /* USER CODE BEGIN 3 */
  }
  /* USER CODE END 3 */
}

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


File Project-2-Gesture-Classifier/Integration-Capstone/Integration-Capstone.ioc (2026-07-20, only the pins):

Mcu.UserName=STM32F411RCTx
PA10.Signal=USART1_RX
PA11.Signal=USB_OTG_FS_DM
PA12.Signal=USB_OTG_FS_DP
PA3.GPIO_Label=LED_BLE
PA3.Signal=GPIO_Output
PA4.GPIO_Label=IMU_CS
PA4.Signal=GPIO_Output
PA5.Signal=SPI1_SCK
PA6.Signal=SPI1_MISO
PA7.Signal=SPI1_MOSI
PA9.Signal=USART1_TX
PB0.GPIO_Label=LED_GESTURE
PB0.Signal=GPIO_Output
PB10.Signal=I2C2_SCL
PB6.Signal=I2C1_SCL
PB7.Signal=I2C1_SDA
PB9.Signal=I2C2_SDA

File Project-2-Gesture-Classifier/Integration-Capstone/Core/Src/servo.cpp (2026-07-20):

#include "servo.h"

static I2C_HandleTypeDef *_hi2c = nullptr;

static void PCA_WriteReg(uint8_t reg, uint8_t val) {
    uint8_t buf[2] = {reg, val};
    HAL_I2C_Master_Transmit(_hi2c, PCA9685_ADDR << 1, buf, 2, 100);
}

static void PCA_SetChannel(uint8_t ch, uint16_t on, uint16_t off) {
    uint8_t buf[5];
    buf[0] = 0x06 + (ch * 4);
    buf[1] = on & 0xFF;
    buf[2] = (on >> 8) & 0xFF;
    buf[3] = off & 0xFF;
    buf[4] = (off >> 8) & 0xFF;
    HAL_I2C_Master_Transmit(_hi2c, PCA9685_ADDR << 1, buf, 5, 100);
}

void Servo_Init(I2C_HandleTypeDef *hi2c) {
    _hi2c = hi2c;
    PCA_WriteReg(PCA9685_MODE1, 0x00);
    HAL_Delay(10);
    // Set prescaler for 50Hz: 25MHz / (4096 * 50) - 1 = 121
    PCA_WriteReg(PCA9685_MODE1, 0x10); // sleep
    PCA_WriteReg(PCA9685_PRESCALE, 121);
    PCA_WriteReg(PCA9685_MODE1, 0x00); // wake
    HAL_Delay(5);
}

// Pulse width: REST=307 (~1.5ms), OPEN=205 (~1ms), CLOSE=410 (~2ms)
void Servo_SetGesture(Gesture gesture) {
    uint16_t pos[6];

    switch (gesture) {
        case GESTURE_REST:
            for (int i = 0; i < 6; i++) pos[i] = 307;
            break;
        case GESTURE_GRIP:
            for (int i = 0; i < 6; i++) pos[i] = 410;
            break;
        case GESTURE_PINCH:
            pos[0] = 410; pos[1] = 410;
            pos[2] = 307; pos[3] = 307;
            pos[4] = 307; pos[5] = 307;
            break;
        case GESTURE_POINT:
            pos[0] = 205; pos[1] = 410;
            pos[2] = 410; pos[3] = 410;
            pos[4] = 410; pos[5] = 307;
            break;
        case GESTURE_PRONATE:
            for (int i = 0; i < 5; i++) pos[i] = 307;
            pos[5] = 205;
            break;
        case GESTURE_SUPINATE:
            for (int i = 0; i < 5; i++) pos[i] = 307;
            pos[5] = 410;
            break;
        default:
            for (int i = 0; i < 6; i++) pos[i] = 307;
            break;
    }

    for (uint8_t i = 0; i < 6; i++) {
        PCA_SetChannel(i, 0, pos[i]);
    }
}

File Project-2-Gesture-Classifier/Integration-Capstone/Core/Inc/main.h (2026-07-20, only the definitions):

#define LED_BLE_Pin GPIO_PIN_3
#define LED_BLE_GPIO_Port GPIOA
#define IMU_CS_Pin GPIO_PIN_4
#define IMU_CS_GPIO_Port GPIOA
#define LED_GESTURE_Pin GPIO_PIN_0
#define LED_GESTURE_GPIO_Port GPIOB

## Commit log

2026-07-07 Add EMG acquisition board
    Dual-channel surface EMG signal acquisition board using INA333
    instrumentation amplifiers, TLV2372 second-stage amplification,
    and ADS1115 16-bit I²C ADC.
    Signal chain per channel: 101x differential gain (INA333) →
    1.6Hz high-pass filter → 4x second stage (TLV2372) → 480Hz
    anti-alias filter → ADS1115 (0x48). Total gain ~404x.
    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
    [EMG-Acquisition-Board-BOM.csv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]
2026-07-07 High-speed Digital — STM32 + SDMMC Data Logger project folder
    An STM32F4-based board with a microSD card slot connected over the 4-bit SDMMC bus. The board is designed to log dual-channel EMG data received over I²C from the EMG acquisition board, writing it to 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
2026-07-09 Add STM32 SDMMC Logger — High-speed digital track #2
    STM32F411RETx (LQFP-64) board with 4-bit SDMMC interface to
    microSD card slot for real-time EMG data logging.
    Key design decisions:
    - LQFP-64 selected over UFQFPN-48 — SDMMC pins not bonded
    out on 48-pin package
    - 47Ω series resistors on all SDMMC signals for reflection
    damping, 10kΩ pull-ups on CMD and DAT0-DAT3 per SD spec
    - Mechanical DET switch used for card detect, not DAT3/CD,
    to avoid data bus conflict
    - 25MHz crystal for USB CDC accuracy, USBLC6-2SC6 ESD
    protection at connector
    - B.Cu solid GND plane only — no F.Cu pour to preserve clean
    return paths under SDMMC and USB signals
    - AMS1117-3.3 LDO from USB VBUS thr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
    [STM32-SDMMC-Logger-Board-BOM.csv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]
2026-07-11 Add Servo Driver Board — Analog/mixed-signal track #2, Project 3
    PCA9685PW-based 16-channel PWM servo controller driving 6 servo
    motors for prosthetic hand actuation over I²C.
    - PCA9685 over STM32 PWM — offloads 6-channel PWM generation,
    frees host MCU for gesture classification and data logging
    - Dual power rail — VSERVO (5-6V) and logic (3.3V) separated
    to isolate servo switching transients from I²C bus
    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
2026-07-12 Project-4-BLE-Module-Board
    An nRF52840-based BLE 5.0 module that receives gesture commands and EMG telemetry from the prosthetic arm system and transmits them wirelessly to a smartphone or PC for monitoring, configuration, and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
    [BLE-Module-Board-BOM.csv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]
2026-07-13 IMU Sensor Fusion Board — Project 5 of Smart Prosthetic Arm
    ICM-42688-P 6-axis IMU board (3-axis gyroscope + accelerometer)
    over high-speed SPI for wrist orientation and motion sensing,
    fused with EMG signals for improved gesture classification.
    [IMU-Sensor-Fusion-Board-BOM.csv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]
2026-07-16 Integration Capstone Board — Project 6 of Smart Prosthetic Arm
    STM32F411RETx central hub board integrating all five Smart
    Prosthetic Arm subsystems — EMG acquisition, servo actuation,
    BLE telemetry, IMU sensor fusion, and gesture classification.
    - Dual I²C bus — I²C1 for EMG/servo/BLE, I²C2 dedicated to
    IMU passthrough to prevent address conflicts and bus loading
    - SPI1 shared between IMU and BLE module with independent CS
    lines — allows 24MHz IMU sampling concurrent with BLE
    - All connector pinouts designed from project start to match
    corresponding headers on each subsystem board exactly
    - 100µF bulk cap at LiPo input for multi-board startup inrush
    -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
    [Integration-Capstone-Board-BOM.csv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]
2026-07-20 Gesture Classifier Firmware — Project 2 of Smart Prosthetic Arm
    Phase 1 threshold-based gesture classifier running on STM32F411.
    Reads dual-channel EMG (ADS1115, I²C) and 6-axis IMU (ICM-42688-P,
    SPI), classifies 6 gestures (REST, GRIP, PINCH, POINT, PRONATE,
    SUPINATE), drives PCA9685 servo controller (I²C) and streams
    telemetry to nRF52840 BLE module (UART).
    Modules: emg.cpp, imu.cpp, classifier.cpp, servo.cpp, ble.cpp
    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
2026-07-20 Smart-Prosthetic-Arm-Projects over view

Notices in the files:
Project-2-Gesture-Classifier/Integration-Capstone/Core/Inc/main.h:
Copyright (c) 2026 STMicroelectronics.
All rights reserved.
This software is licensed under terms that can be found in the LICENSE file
